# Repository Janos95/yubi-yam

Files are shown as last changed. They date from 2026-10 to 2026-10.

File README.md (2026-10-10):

# yubi-yam

Toyota / AIRoA's [YUBI](https://yubi.airoa.io/) robot gripper, adapted to the
[I2RT YAM](https://i2rt.com/products/yam-6-dof-arm) arm and driven by the DM4310 from
the YAM's stock gripper. It runs on the arm's own CAN bus and 24 V, so there's no
Dynamixel, no U2D2, no extra power supply and no extra cable down the arm.

The fingers, gears, camera and camera mount are Toyota's design, unchanged. So the
wrist camera sees the same thing as on a YUBI handheld, and data collected with the
YUBI glove (or Toyota's dataset) matches what this gripper sees on the robot.

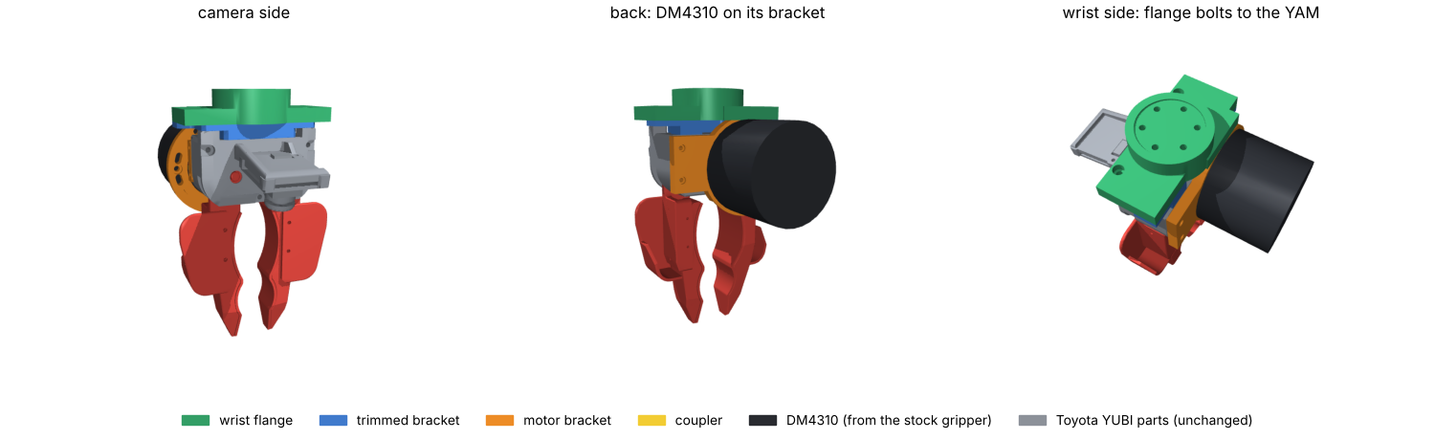
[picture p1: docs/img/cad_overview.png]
CAD overview


## Status

Designed and simulated, **not built yet**.

| What | How it was checked | Result |
|---|---|---|
| New parts fit Toyota's parts and the motor | exact B-rep boolean intersection, every pair (`cad/build.py`) | no overlap |
| Finger travel | exact-mesh collision sweep of both fingers (`sim/finger_sweep.py`) | closed −5.5° (pads touch) to open 36°: **47 mm** between pads, 41.5° of motor travel; new parts never limit it |
| i2RT SDK integration | patch + config installed into a copy of the SDK, then `get_yam_robot(gripper_type=YUBI_4310, sim=True)` | gripper command 0 → 1 drives the finger joint closed → open |
| Grasping | MuJoCo physics: reach down, close on a 30 mm, 50 g cube, lift 10 cm | cube lifts 10 cm, ~17 N pad force at the default gain |
| Reach | exact-mesh collision of the gripper against the arm links over 2,067 poses, compared with the stock gripper | about the same as stock: 256 vs 261 colliding pose/link pairs, all at extreme joint combinations |

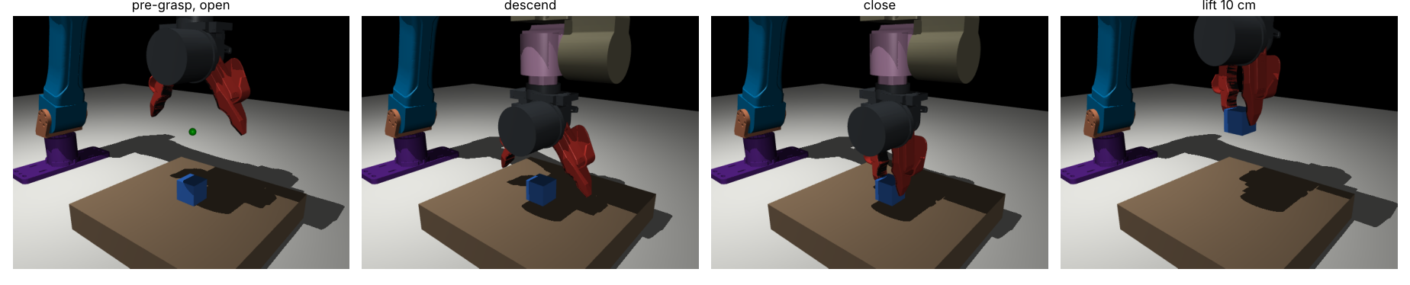
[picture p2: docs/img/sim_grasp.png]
Simulated grasp

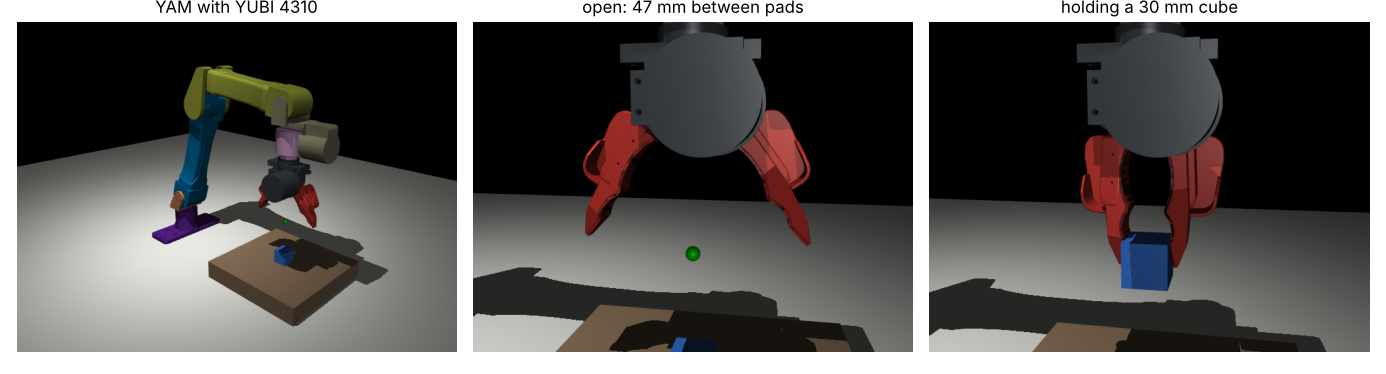
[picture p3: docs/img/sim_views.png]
Simulated views


### Assumptions to check on the real arm

**Checked on the real gripper motor (Oct 9).** The YAM's gripper motor (label
RD-J10D) has the DM4310 face the parts assume: housing Ø57, rotor Ø35, 6× M3 on a
27 mm circle in the rotor (≥7.5 deep), 6× M3 on a 50 mm circle in the front ring
(~4.8 deep). It also has locating pins the reference model lacked: 2× Ø4 on the rotor
(4.2 proud, 23.1 mm circle, 120° apart) and 2× Ø3 on the ring (5.5 proud, opposite
each other, 15° from a screw hole). The coupler has pockets for the rotor pins and the
motor bracket has slots for the ring pins.
The wrist flange also has pockets for the same Ø4 pins, in case the wrist output is
the same motor face (still to confirm once the gripper motor is off the arm).

1. **Wrist screw pattern.** i2RT doesn't publish it, and their meshes have no holes.
   The flange assumes the gripper bolts straight onto the wrist's DM4310 rotor
   (6× M3 on a 27 mm circle around a 35 mm boss); the YAM's last link is 57 mm wide,
   the 4310's diameter. Take the stock gripper off and look. If it differs, change
   `WristInterface` at the top of `cad/build.py` and run `./run_all.sh`. Nothing else
   depends on it.
2. **Wrist face position.** The sim puts the flange face where i2RT's gripper frame
   starts. If the real face sits a few mm away, the tool point in sim is off by that
   much; the hardware is unaffected.
3. **Motor polarity.** Closing should increase the motor reading, as on the stock
   gripper. If the fingers open when commanded closed, set `motor_direction: -1` in
   `yubi_4310.yml`.
4. **Grip force.** `motor_kp: 10` gives roughly 15 N at the pads per N·m of motor
   torque error. Tune it on the real gripper.

## What changes from Toyota's design

| Toyota part | Here |
|---|---|
| Dynamixel XM430-W350-R | DM4310 from the stock YAM gripper |
| Dynamixel horn | `coupler`: DM4310 rotor (6× M3, PCD 27) → YUBI gear shaft. Copies the horn interface, so Toyota's shaft and screws stay unchanged |
| `BRACKET_DYNAMIXEL` | `motor_bracket`: holds the 4310 by its front ring and bolts to the case's existing M2 inserts; the side tab is Toyota's geometry. Has a relief for the thick right finger pad, which reaches 3 mm behind the case |
| `BRACKET_GRIPPER` (machined) | `bracket_trimmed`: the same part, cut back where the bigger motor sits; printable |
| `UR5e_FLANGE` | `yam_flange`: YAM wrist → bracket; also supports the motor bracket from below |

Everything else is built exactly as in Toyota's
[YUBI gripper assembly guide](https://github.com/Toyota/yubi-hw/tree/main/docs/AssemblyInstruction).

The 4310 is bigger and heavier than the Dynamixel (Ø57 × 46 mm, 325 g vs 82 g), so it
hangs behind the case. The whole gripper comes out at about 0.63 kg (stock linear
gripper: about 0.70 kg), with the grasp point 143 mm from the wrist face (stock: 145 mm).

## Build

> **Weekend / first build:** a fully printed version of the gripper and the gloves,
> using only parts available in the US within a couple of days, is described in
> [docs/PRINTED_PROTOTYPE.md](docs/PRINTED_PROTOTYPE.md). The sections below are the
> proper build.

### Print

STEP and STL files are in `cad/out/` (in Toyota's assembly coordinates; STEP is best
for re-orienting in a slicer). PETG or PLA+, 3 walls.

| Part | Orientation | Infill | Note |
|---|---|---|---|
| `yam_flange` | wrist face down | 50 % | |
| `motor_bracket` | motor side down (side tab up) | 60 % | carries the motor's torque |
| `bracket_trimmed` | flat, as Toyota's | 50 % | or machine it in aluminium like Toyota |
| `coupler` | rotor side down | 100 % | or machine it in aluminium; it carries the full gripper torque |

Plus Toyota's printed gripper parts (case, upper plate, fingers, pads, flaps), per
their BOM and print settings.

### Hardware beyond Toyota's BOM

The full shopping list, with MISUMI part numbers and US sources, is in
[docs/BOM_US.md](docs/BOM_US.md).
The [proposed October 9 shopping list](docs/SHOPPING_LIST_2026-10-09.md) records the
prepared vendor carts, printed-prototype substitutions, Hayward pickup and
unconfirmed delivery details. Nothing has been ordered.

| Joint | Qty | Fastener |
|---|---|---|
| wrist flange → YAM wrist | 6 | M3×10 socket head (if the wrist is the assumed 4310 pattern) |
| coupler → DM4310 rotor | 6 | M3×6 low head (DIN 7984) |
| DM4310 → motor bracket | 4 | M3×8 low head (DIN 7984) |
| motor bracket → case back | 2 | M2×8 low head, into the case's existing M2 inserts |
| flange + bracket → upper plate | 2 | M3×12 socket head (replaces Toyota's M3×8 there) |
| inserts | 4 + 2 | M2 heat-set, 3.0 mm OD × 3 mm (as Toyota's SB-203030) in the coupler; M3 heat-set, 4 mm OD × 5 mm in the flange |

Reused from Toyota's BOM: the shaft-to-horn screws (now into the coupler), the
side-tab screws, and the two bracket screws at the flange's ears. Not needed: the
Dynamixel and its screws, the UR5e flange and its screws and pins.

### Assemble

1. Take the stock gripper off the YAM and check the wrist pattern (see above). Take
   the DM4310 out of the stock gripper.
2. Coupler onto the 4310 rotor (6× M3×6). 4310 onto the motor bracket (4× M3×8,
   heads in the counterbores on the case side).
3. Toyota's gear shaft onto the coupler with its 4 M2 screws, as it went onto the horn.
4. Build Toyota's gripper with `bracket_trimmed` in place of `BRACKET_GRIPPER`. Where
   their guide fits the Dynamixel, slide the shaft in and screw the motor bracket to
   the case (2× M2 at the back, 2× M2 into the side).
5. Wrist flange onto the YAM (6× M3×10).
6. Gripper onto the flange: 2× M3×8 from the top through the bracket ears, 2× M3×12
   from below through flange and bracket into the upper plate.
7. Plug the 4310 into the wrist connector the stock gripper used, and run the camera's
   USB cable along the arm.

## Software

```bash
git clone https://github.com/i2rt-robotics/i2rt
./sdk/install.sh ../i2rt        # 4-line patch + config + MuJoCo model
```

```python
from i2rt.robots.get_robot import get_yam_robot
from i2rt.robots.utils import GripperType

robot = get_yam_robot(channel="can0", gripper_type=GripperType.YUBI_4310)
```

It's the same motor on the same CAN ID as the stock gripper. On first start the SDK
calibrates the gripper the same way it does the stock one: it drives gently to the
closed stop (pads touching) and the open stop (fingers against the case). Because the
travel is less than one motor turn, you can then write the measured limits into
`gripper_limits` in `yubi_4310.yml` and set `needs_calibration: false`.

The patch was made against i2rt `120c3c8` (pinned in `third_party/i2rt`).

## Reproduce

```bash
git submodule update --init
pip install -r requirements.txt
./run_all.sh
```

| Step | Script | Output |
|---|---|---|
| parts, interference check, sim meshes | `cad/build.py` | `cad/out/`, `sim/assets/` |
| finger travel | `sim/finger_sweep.py` | `sim/finger_travel.json` |
| i2RT model + config | `sim/build_model.py` | `sdk/overlay/` |
| SDK, grasp and reach checks | `sim/check_sim.py` | `sim/check_report.json`, `docs/img/` |

All dimensions come from published CAD:

- **YUBI:** Toyota's STEP files, exact.
- **YAM:** i2RT's MuJoCo models.
- **DM4310:** checked against Damiao's model as published in OpenArm v1.1 (used for
  measurements only; this repo doesn't contain it).

## Layout

```
cad/build.py           parametric parts, built from Toyota's CAD
cad/out/               STEP + STL of the new parts, build_summary.json
cad/printed.py         fully printed prototype parts -> cad/out/printed/
cad/vendor/            Adafruit AS5600 board model (MIT) for the glove fit check
sim/                   travel sweep, i2RT model generator, checks
sdk/                   i2RT patch, overlay (config, model, meshes), install.sh
docs/                  parts list, printed-prototype guide, figures
third_party/yubi-hw    Toyota's YUBI hardware (submodule)
third_party/i2rt       i2RT SDK (submodule)
```

## Licence

Hardware design files (`cad/`, the meshes in `sim/assets/` and `sdk/overlay/`) are
derived from Toyota's YUBI and released under
[CERN-OHL-W-2.0](LICENSE), like the original. Code is under [MIT](LICENSE-MIT). See
[NOTICE.md](NOTICE.md) for credits.

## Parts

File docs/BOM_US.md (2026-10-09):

# Parts list — US sourcing

Scope: **one YAM robot gripper + one right-hand YUBI data-collection glove**.
Target: **delivery to San Francisco 94158, or Bay Area pickup, by Friday October 9, 2026**.
Prices initially checked October 6, 2026 (Pacific time); selected cart contents and
prices updated October 7. USD, before tax unless stated. The purchase quantities
cover **one robot and one right-hand glove**, plus a spare Adafruit 6357 board and
Radial 9042 magnet (two of each bought). Buy one of each shared pack. Status October 8
evening: the M5 screws are bought; Friday arrival is no longer possible for MISUMI,
McMaster or DigiKey (expect Monday October 12). See the shopping list for details.
Nothing in this list has been ordered. Stock and delivery estimates must be checked again at checkout.

See the [proposed October 9 shopping list](SHOPPING_LIST_2026-10-09.md) for the prepared
carts and the [printed prototype](PRINTED_PROTOTYPE.md) for the weekend substitutions.
The prototype uses printed drive parts/adapters, three 695ZZ bearings with printed
shims, and a stock M5 socket-head screw. Keep the late precision parts in a separate
proper-build shipment.

**Proper-build sourcing is not complete under the Friday constraint.** The exact
gears and stepped shaft currently ship after Friday. Custom machining, bearings, inserts and several
small precision parts still need confirmation. A catalog link does not mean a part is
available in time. We have not established a lowest delivered price for the whole build.

Compare **whole-order cost**: required packs + shipping + rush/setup charges + tax or
import fees. Consolidate orders, but do not let one backordered item delay stocked items.
“Ships October 8” is not “arrives October 8.” MISUMI express eligibility is part-specific;
the general express-service page is not a delivery commitment.

## Already available / excluded

- Reuse the stock YAM gripper's **DM4310**; no Dynamixel, U2D2 or separate Dynamixel power supply.
- Computer, recording software and USB connections are already available.
- Reuse the **Quest 3** and its right Touch Plus controller, assuming the original controller is available.
- Wear the headset for the first iteration: **no headset mount, extrusion rig or chest mount** to buy.
- The **controller holder attached to the glove** is still required; it is a printed part.
- This is a one-glove hardware list, not a claim that Toyota's default two-hand recording configuration
  already works with one glove and a moving headset. Check the selected recording configuration,
  world-frame controller poses, calibration and synchronization before collecting training data.

Sources: [Toyota robot BOM](https://github.com/Toyota/yubi-hw/blob/main/docs/BOM/YUBI%20Gripper_DYNAMIXEL_BOM.md),
[Toyota glove BOM](https://github.com/Toyota/yubi-hw/blob/main/docs/BOM/YUBI%20Glove%20Assy_BOM.md),
[recording software](https://github.com/airoa-org/yubi-sw).

## Print versus machine

The preferred machining set is **five parts**, quantity one each. The two finger
attachments are a separately priced upgrade. No machining order should use the
print-oriented adapter STEP files without resolving their threaded features.

| Part | Process for this build | Source / release requirement |
|---|---|---|
| Toyota `GEAR SHAFT` | Machine, A2024 as Toyota specifies | [Toyota STEP](https://github.com/Toyota/yubi-hw/tree/main/STEP/gripper); preserve journal fits and coaxiality. Printing is only an assembly mock-up, not an accuracy-equivalent substitute. |
| YAM `coupler` | Prefer machined aluminum | [STEP](../cad/out/coupler.step); convert four M2 heat-set-insert pockets to properly designed metal threads. |
| YAM `motor_bracket` | Prefer machined aluminum | [STEP](../cad/out/motor_bracket.step); load-bearing motor support. |
| YAM `bracket_trimmed` | Prefer machined aluminum | [STEP](../cad/out/bracket_trimmed.step); replaces Toyota's machined `BRACKET_GRIPPER`. |
| YAM `yam_flange` | Prefer machined aluminum | [STEP](../cad/out/yam_flange.step); convert two M3 insert pockets to metal threads and measure the real wrist before release. |
| Toyota `FINGER ATTACHMENT_L/R` (2) | Optional A2024 machining upgrade | Toyota allows machined A2024 or printed PLA. Price separately; printing does not guarantee equal stiffness/precision. |
| Robot case, upper plate/camera bracket, three pad bodies, two flaps | Print as in Toyota's design | [STL/gripper](https://github.com/Toyota/yubi-hw/tree/main/STL/gripper); inspect bearing seats and assembly fit. |
| Glove upper/under plates, two geared fingers, two flaps, grip, right controller holder, PCB/cable covers | Print; use the adapted AS5600 upper plate | [Printed prototype](PRINTED_PROTOTYPE.md) for `glove_upper_plate_as5600`; other parts from [STL/glove](https://github.com/Toyota/yubi-hw/tree/main/STL/glove). Right hand uses `FINGER with Gear_t30_R` and `FINGER with Gear_t20_L`. No bought metal gears for the glove. |

The YAM adaptation is designed/simulated, **not physically validated**. Its wrist pattern
(six M3 holes on a 27 mm pitch circle and a 35 mm boss) is an assumption pending measurement.
The coupler/flange insert pockets are not suitable tap-drill holes as exported. Request
critical fits, tolerances and material approval before manufacture; 6061-T6 is a quote
candidate for new adapters, not an automatic substitute for Toyota's A2024 parts.

### Local machining candidates

| Shop | Relevant published capability | Price + Friday status |
|---|---|---|
| [finalREV, Berkeley](https://www.finalrev.com/services/millturn) | Advertises same-day Bay Area parts, single-part minimum and local pickup. [5-axis service](https://www.finalrev.com/services/5-axis-cnc) for larger/prismatic work. | **RFQ sent October 6; response pending.** Millturn stock limit is 1-inch round; the gear shaft fits that diameter, the 32 mm gear does not. Confirm A2024 availability. |
| [RivCut, Union City](https://www.rivcut.com/) | Milling/turning, 2024/6061/7075 aluminum; prototypes advertised as fast as three business days; pickup by appointment. | **Quote required.** No job-specific price, capacity reservation or Friday promise obtained. |
| [twentyfour26, San Francisco](https://twentyfour26.com/) | Rapid prismatic machining in 6061-T6. | Conditional bracket backup: minimum internal radius and standard tolerances need checking against these parts. **Quote required.** |

Request one combined quote for the five preferred parts, the two optional finger
attachments separately, and modification/machining of the late bought parts below.
Require itemized setup, design revision, inspection, rush and pickup/delivery charges.
As-machined/deburred finish avoids unnecessary cosmetic finishing cost. Quotes are not
manufacturing authorization. **finalREV RFQ sent October 6, 2026** with the five-part
base set, two optional finger attachments, source CAD and catalog-part modification
requests. Requested itemized pricing, total pickup/delivery costs and committed Friday
October 9 availability. **Awaiting response; price and Friday capacity are unconfirmed.**
Other supplier RFQs have not been sent. No machining order has been placed.

## Robot motion and alignment parts

All quantities below are for the robot only.

| Qty | Required part / important geometry | Source and observed parts price | Friday status / next route |
|---|---|---|---|
| 2 | `GEAKB1.0-30-6-B-8N-QFC17-M3-LL`; module 1, 30 teeth, 6 mm face, keyed Ø8 bore, QFC17 M3 face-hole feature | [MISUMI USA](https://us.misumi-ec.com/vona2/detail/110300428430/?HissuCode=GEAKB1.0-30-6-B-8N-QFC17-M3-LL), $42.51 each / **$85.02** | **Late:** October 7 cart showed ship October 14. Ask for part-specific express or local modification of a compatible stock gear. Generic 30T/8 mm gears are not drop-in replacements. |
| 1 | `SSFRHQ8-20-F6-P5-T6-Q5-KC8-A12`, configured Ø8 stepped/keyed left finger shaft | [MISUMI USA](https://us.misumi-ec.com/vona2/detail/110300088230/?HissuCode=SSFRHQ8-20-F6-P5-T6-Q5-A12-KC8), **$26.71** | **Late:** displayed ship October 14. Local turning/keyway quote must use the full configured drawing, not only overall diameter/length. |
| 3 | `MTA05-13ZZ DBS`, NSK Micro/ISC angular-contact bearing, nominal 5 × 13 × 5 mm | [MISUMI USA](https://us.misumi-ec.com/vona2/detail/221000531127/?HissuCode=MTA05-13ZZ%20DBS), $23.58 each / **$70.74**; [Volition](https://www.govolition.com/product/V52-MTA05-13ZZ%20DBS) lists the same MISUMI supply | **Unconfirmed:** October 7 cart has no ship date. Volition's estimated three days to ship is not Friday delivery or independent stock. Preserve these bearings for the proper build; 695ZZ plus a printed shim is only the documented prototype stand-in. |
| 3 | `WSSAB10-5-1`, nominal Ø10 OD / Ø5 ID / 1 mm thickness | [MISUMI USA](https://us.misumi-ec.com/vona2/detail/110302677010/?HissuCode=WSSAB10-5-1), $23.42 each / **$70.26** | **Late:** ship October 10. Seek a stocked precision spacer or add to local machining quote. Generic M5 washers are not automatically equivalent. |
| 2 | `KEG3-8`, 3 × 3 × 8 mm, one round end and one square end | [MISUMI USA](https://us.misumi-ec.com/vona2/detail/110302681730/?HissuCode=KEG3-8), $3.90 each / **$7.80**; [Huyett 330303-008](https://www.huyett.com/330303-008) has matching nominal Form AB geometry | **Late** at MISUMI: ship October 10. Huyett is special-order with a $50 minimum, not a verified fast/cheap alternative. Ask shop to supply/finish keys. |
| 1 | Round locating pin `JPBPB2-3` | [MISUMI USA](https://us.misumi-ec.com/vona2/detail/110300557320/?HissuCode=JPBPB2-3), **$7.05** | **Stock/ship candidate:** October 8 dispatch; shipping cost and arrival unquoted. |
| 1 | Diamond locating pin `JPDPB2-3` | [MISUMI USA](https://us.misumi-ec.com/vona2/detail/110300557320/?HissuCode=JPDPB2-3), **$9.89** | **Late:** ship October 15. Ask about a stocked same-fit material variant or local modification of a round pin to the drawing. |

**Precision corrections:** the locating pins are not ordinary Ø2 × 3 mm dowels:
they have a Ø2 press-fit shank, Ø3 positioning head, 4 mm mounting length and 3 mm
positioning length. Preserve the round/diamond pairing. The original washer has ID
5.1–5.3 mm, OD 9.8–10 mm and thickness 1 ±0.05 mm. Verify any replacement's tolerance.

**Cheaper spacer candidate:** [KB3D SS-5101-50 DIN 988 shim rings](https://kb-3d.com/store/inserts-fasteners-adhesives/288-5x10x1mm-shim-ring-washer-pack-of-50-din988-1634423113147.html)
are **$3.79 per pack of 50**, with **two packs in stock** in the retailer listing.
Nominal dimensions are 5 × 10 × 1 mm; stainless steel replaces the original aluminum.
Confirm actual ID/OD/thickness tolerances, shaft/fillet clearance and flat seating
before using them as WSSAB replacements. They are a credible low-cost precision-shim
candidate, not an ordinary M5 washer. Shipping from Ohio must be expedited and quoted;
the retailer publishes a 2 pm Eastern same-day cutoff, not a Friday-arrival guarantee.

[NSK's catalog](https://www.nskmicro.co.jp/english/download/catalog_pdf/bearing/croxy_en.pdf)
explains the angular-contact/preload design. Radwell lists `MTA05-13ZZ DB`, a different
paired configuration, not the specified `DBS`; buying/separating those is **not an
approved substitute** without NSK confirmation. No precision-preserving printed
bearing, key or shaft substitute is selected.

**Concrete gear-blank route for a shop to quote:**
[KHK SSA1-30](https://catalog.khkgears.us/item/spur-gears/hubless-spur-gears-ssa/ssa1-30)
is **$13.45 each / $26.90 for two**, with **five on hand** at the original KHK USA check.
It is unhardened S45C steel, module 1, 30 teeth, 20° pressure angle, Ø8 plain bore,
Ø32 outside diameter, **10 mm face width** and JIS N8 quality. It needs a shop's
geometry review, width reduction to 6 mm, keyway and the configured face features;
tooth accuracy/backlash must also meet the application. It is **a machining blank,
not a drop-in replacement**. Overnight freight and machining/pickup remain unquoted.
Grainger lists this blank for $19.99 but showed October 22 delivery, so its offer
does not meet the deadline. Do not order blanks until a shop accepts the conversion.

## Cameras, glove electronics and shared consumables

| Qty to buy | Part | Source / observed price | Delivery / compatibility |
|---|---|---|---|
| 2 | ELP `USBFHD01M-L180` camera: one robot, one glove | [Amazon US](https://www.amazon.com/dp/B00LQ854AG), **$44.99 each new / $89.98 total** | October 7 check with quantity 2 showed Friday October 9 to 94158 with Prime. The cheaper used-like-new offer now misses Friday. Guest shipping misses Friday; sign-in and selected-offer confirmation required. |
| 1 | Seeed XIAO ESP32C6 `113991254` | [DigiKey](https://www.digikey.com/en/products/detail/seeed-technology-co-ltd/113991254/24613066), **$5.38** | Immediate availability in the prepared cart; combine with perfboard/magnets. Delivery conditional on dispatch and chosen shipping. |
| 2 (1 spare) | Adafruit `6357` AS5600 breakout | [DigiKey 1528-6357-ND](https://www.digikey.com/en/products/detail/adafruit-industries-llc/6357/26832926), **$5.95 each / $11.90** | Immediate availability in the overnight DigiKey cart. Use `glove_upper_plate_as5600` and four extra M2×6 screws. Separate Adafruit cart remains empty. Actual Friday arrival remains unconfirmed. |
| 2 (1 spare) | Diametric encoder magnet, Radial Magnets `9042`, Ø6 × 2.5 mm, N35 | [DigiKey](https://www.digikey.com/en/products/detail/radial-magnets-inc/9042/5640338), **$0.63 each / $1.26** | Immediate availability in the prepared cart. Board ships without a magnet. Use the documented 2 mm sensor gap. Must be **diametrically**, not axially, magnetized. |
| 1 | SparkFun `PRT-08808` perfboard, 25.4 × 25.4 mm | [DigiKey](https://www.digikey.com/en/products/detail/sparkfun-electronics/08808/7387401), **$2.96** | Exact original perfboard; Immediate availability in the prepared cart. |
| As needed | Pin headers / short hookup wires / solder | Check XIAO package and existing supplies; Toyota lists four header pieces | Header installation is required. Avoid ordering a new soldering kit unless missing. |
| 0 (already owned) | Grip rubber; original 1.5 mm `PX-10H15 HYPER V` | Janos's Everbilt rubber packing sheet, 6 × 6 in × 1/16 in (Home Depot 1006950747), already tested on wires. Fallback if grip is insufficient: [RAPOLL solid neoprene, 12 × 12 in × 1/16 in](https://www.amazon.com/dp/B0BKQRN7S6), $6.89 | **Thickness substitution** (nominal 1.59 mm vs 1.5 mm): recalibrate the jaw's closed position. Glue with Loctite Ultra Gel Control. |
| 1 alternative pack | Nominal 1.5 mm silicone sheet | [PATIKIL, five Ø100 mm discs](https://www.amazon.com/dp/B0G2JR4VFQ), **$9.21 + free Prime shipping**, Thursday shown in search | Alternative to neoprene, not an additional purchase. Check cutting layout and suitable silicone adhesive; grip performance is unvalidated. [Original Hyper V](https://nisshinrubber-metalcraft.com/products/hyperv%E3%82%B7%E3%83%BC%E3%83%88-px-10h-15-%E8%80%90%E6%B2%B9w270-l270-h1-5mm) remains the reference. |
| 1 band from pack | Return band, original Japanese No.16 | [MOWPOG #16 pack](https://www.amazon.com/dp/B0FCM95WH7), **$5.99 + free Prime shipping**, Thursday October 8 shown | Listing specifies 2.37 in folded length and 0.06 in width/thickness. Check return force and full travel; the size number alone is not equivalence. Reusing a suitable existing band avoids buying hundreds for one glove. |
| 0 | USB data cables/connections | Already available | Verify connector ends on the actual camera and XIAO; do not blindly order two USB-C cables. |

[DigiKey US shipping rates](https://www.digikey.com/en/help-support/delivery-information/delivery-time-and-cost):
two-day air **$13.99/order**, overnight PM **$26.99/order**. The prepared cart contains
one each of XIAO and perfboard plus two each of Adafruit 6357 and Radial 9042 (one
spare), **$21.50 parts**, with **FedEx Overnight P.M. selected**. Estimated tariff is
about **$0.68** (October 7 estimate scaled; recheck), for about **$49.17 before tax**.
Friday arrival to 94158 is not displayed. DigiKey warns that processing may take an
extra business day: overnight requires dispatch by Thursday October 8. `MIKROE-4204`
does not fit the glove and is removed; the `AS5601-SO_EK_AB` fallback is dropped too.
The separate Adafruit cart remains empty; the 6357 board is in the DigiKey cart.
Solder VIN (3.3 V), GND, SCL and SDA directly to the XIAO; no QT cable is needed.

## Screws — consolidated quantities for both builds

Counts include one robot and one right glove. Standard socket heads and low/ultra-low
heads are separate requirements. Lengths are under-head lengths. Ordinary screws use
M2 × 0.4, M2.5 × 0.45 and M3 × 0.5 threads.

| Robot | Glove | Buy/use total | Screw | Source / current status |
|---:|---:|---:|---|---|
| 4 | 8 | 12 | M2 × 6, standard socket head | [mxuteuk M2-only 520-piece kit](https://www.amazon.com/dp/B0C6M6MJ8M), **$8.99**, explicitly lists **30 M2×6**; Friday with Prime shown. Glove count includes four extra AS5600 mount screws. Original mixed kit removed: it contains M2×12/16, no M2×6. |
| 2 | 2 | 4 | M2.5 × 6, standard socket head | Included in the VGBUY M2.5 kit below; [McMaster 91290A101](https://www.mcmaster.com/91290A101/) fallback, $11.81/50. |
| 0 | 2 | 2 | M2.5 × 8, standard socket head | Included in the VGBUY M2.5 kit below; [McMaster 91290A006](https://www.mcmaster.com/91290A006/) fallback, $11.71/100. |
| 4 | 0 | 4 | M2.5 × 10, standard socket head | [VGBUY M2.5 1001-piece kit](https://www.amazon.com/dp/B0FJ1YMG3J), **$9.99 guest cart**, advertised Prime deal $7.99; October 8 with Prime shown. Also covers M2.5 × 6/8. [McMaster 91290A007](https://www.mcmaster.com/91290A007/) fallback is $11.03/100. |
| 3 | 3 | 6 | M2.5 × 15, standard socket head | [McMaster 91290A009](https://www.mcmaster.com/91290A009/), **$4.25/10**, Thursday delivery shown; final shipping unquoted. |
| 0 | 1 | 1 | M3 × 6, standard socket head | Included in the ALLWIN M3 kit below. |
| 4 | 0 | 4 | M3 × 8, standard socket head | Included in the ALLWIN M3 kit below. |
| 6 | 0 | 6 | M3 × 10, standard socket head | [ALLWIN M3 400-piece kit](https://www.amazon.com/dp/B0F5QKDW7Y), **$5.79 guest cart**, advertised Prime deal $4.63; October 9 with Prime shown. Includes 30 screws of this length plus M3 × 6/8/12/16/20. |
| 2 | 0 | 2 | M3 × 12, standard socket head | Included in the ALLWIN M3 kit above. |
| 6 | 0 | 6 | M2 × 5, ultra-low head: Ø4 × 0.5 mm head | [MISUMI CBSTBR2-5](https://us.misumi-ec.com/vona2/detail/110302280540/?HissuCode=CBSTBR2-5), **$5.24 each / $31.44**; same steel/geometry, black nickel instead of white. October 8 dispatch shown. Original CBSTNR2-5 ships October 10. |
| 4 | 0 | 4 | M3 × 8, ultra-low head: Ø6 × 0.8 mm head | [MISUMI CBSTNR3-8](https://us.misumi-ec.com/vona2/detail/110302280540/?HissuCode=CBSTNR3-8), **$5.05 each / $20.20**, October 8 dispatch shown. |
| 6 | 0 | 6 | M3 × 6, low head for rotor → coupler | [McMaster 92855A307](https://www.mcmaster.com/92855A307/), **$7.30/25**, Ø5.5 × 2 mm head, Thursday 7–9 am shown. |
| 4 | 0 | 4 | M3 × 8, low head for stator → motor bracket | [McMaster 92855A309](https://www.mcmaster.com/92855A309/), **$7.55/25**, 18-8 stainless, DIN 7984, Ø5.5 × 2 mm head, Thursday shown. [Alloy-steel 93070A064](https://www.mcmaster.com/93070A064/) is $13.62/50 if higher strength is required. |
| 2 | 0 | 2 | M2 × 8, low head for motor bracket → case back | [McMaster 92855A839](https://www.mcmaster.com/92855A839/), **$20.40/10**, Ø3.8 × 1.35 mm head, Thursday 7–9 am shown. |

McMaster dates above are displayed site estimates; the final destination/shipping
charge was not entered or quoted. MISUMI stocked rows also require a delivered quote.
The original [888-piece mixed kit](https://www.amazon.com/dp/B0G8F366MV) has only
M2×12/16 in its size diagram and cannot cover M2×6. The replacement M2-only kit's
packaging text explicitly lists 30 M2×6, leaving **18 spare** after the required 12.
Its size diagram has mislabeled entries, so the count is taken from the packaging
text. The two CBSTNR3-5 mount screws per glove are no longer required by the AS5600
plate. Do not buy every fallback pack as well as the selected kits.

The prepared standard-screw combination is the **$8.99 M2 kit + $9.99 M2.5 kit +
$5.79 M3 kit + $4.25 McMaster M2.5 × 15 pack = $29.02** before freight/tax.
Advertised Prime deals of $7.99 for M2.5 and $4.63 for M3 would reduce it to **$25.86**
if applied after sign-in. All three Amazon kits show delivery by Friday with Prime,
**plus the McMaster order's shipping and tax**.
This covers every standard screw length above; special low/ultra-low heads are extra.
Amazon search dates must be rechecked for the selected offer at checkout. Prime sale
prices and the displayed nightly delivery cutoffs may expire.

DIN 7984 and ordinary “low head” screws do **not** replace Toyota's ultra-low heads.
The new adapter counterbores and screw engagement still need checking on the machining
revision. Follow the manufacturer's reduced tightening torque for ultra-low heads.
The listed 18-8 low-head screws have 70,000 psi tensile strength; confirm required
joint preload/strength before substituting them for higher-strength alloy steel.

## Printed-prototype stand-ins

These are temporary purchases for the [printed prototype](PRINTED_PROTOTYPE.md),
not precision-equivalent replacements for the proper-build parts.

| Buy qty | Stand-in | Source / price | Fulfillment / use |
|---|---|---|---|
| 1 pack of 10; use 3 | 695ZZ deep-groove bearings, 5 × 13 × 4 mm | [KABOBEARING](https://www.amazon.com/dp/B0CRP3K8ZF), **$6.99** guest cart; advertised Prime deal $5.59 | October 8 with Prime shown. Cheapest matching Friday-capable pack found in the ascending-price search. Print three `bearing_shim_1mm` parts under the outer races. |
| 1 pack of 2; use 1 | M5 × 0.8 × 70 mm socket-head cap screw | [Home Depot Everbilt 844868, SKU 540934](https://www.homedepot.com/p/204283625), **$3.97** | **Bought** at Hayward on October 7. Use one screw and keep one spare. |

## Inserts for printed parts

| Robot | Glove | Total | Original specification | Sourcing status |
|---:|---:|---:|---|---|
| 4 | 0 | 4 | `SB-203030`: M2, nominal body Ø3 / knurl Ø3.3, length 3 mm | Exact US stock unresolved; generic M2 insert must match the actual printed hole and installation recommendation. |
| 5 | 5 | 10 | Toyota calls out `SB-264040`, nominal body Ø4 / knurl Ø4.3, length 4 mm | **Thread discrepancy to resolve:** assembly uses M2.5 screws; current Tokai catalog calls M2.5 `SB-254040`, while `SB-264040` is M2.6. Do not order M2.6 blindly. |
| 4 | 0 | 4 | `SB-304550`: M3, nominal body Ø4.5 / knurl Ø4.8, length 5 mm | Exact US stock unresolved. Not “M3 Ø4 × 5”; check fit before choosing another brand. |
| 0 | 2 | 2 | `SB-304540`: M3, nominal body Ø4.5 / knurl Ø4.8, length 4 mm | Exact US stock unresolved. |

[Tokai dimensions](https://tokai-mmc.co.jp/insert/seihin_sb.html) and
[catalog](https://www.tokai-mmc.co.jp/insert/catalog/SB.pdf).
A different insert is acceptable only after adapting/checking the printed hole, pullout
resistance and surrounding wall; “any heat-set kit works” was incorrect.

**Fast US candidates, requiring printed-hole adaptation/fit validation:**

- [KADRICK 520-piece kit](https://www.amazon.com/dp/B0D5V3TZLB), **$15.98**, includes
  M2 × 3 mm long (listed OD 3 mm), M3 × 4 mm and M3 × 5 mm (listed OD 4.5 mm).
- [KADRICK M2/M2.5 300-piece kit](https://www.amazon.com/dp/B0FD7DQS8Y), **$9.99**,
  includes M2.5 × 4 mm long, listed OD 3.5 mm, thread pitch 0.45 mm.
- Both product pages showed **free Prime delivery Thursday October 8** to 94158.
  Together **$25.97 delivered before tax** at the checked offers. These are not the
  original Tokai insert shapes/diameters. Preserve hole centers, select pilot holes
  for these inserts, and check wall thickness, installation, screw engagement and
  pullout/torque resistance before using them in load-bearing printed parts. Do not
  install a loose insert into the original larger hole and call it equivalent.

This closes the supply search for candidate inserts, **not their fit/strength
qualification**. Exact Tokai US stock remains unresolved. A cheaper $9.99 Dianrui
assortment was rejected as a complete kit because it lacks the needed M2 × 3 and
M3 × 5 lengths; the $9.99 KADRICK M3-only kit showed October 12 delivery.

For the **machined coupler/flange**, metal threads replace the adapter inserts.
For the printed pair, add **four M2×3 and two M3×5 inserts** to the base counts.
The selected single kits cover **8 M2×3 / 60 available**, **10 M2.5×4 / 60**,
**6 M3×5 / 50**, and **2 M3×4 / 50**. These counts include the printed adapters;
keep the existing printed-hole fit/strength checks.

## Glove-only adjustment hardware

| Qty | Part | Source / parts price | Friday status |
|---|---|---|---|
| 4 | `JZF8-5` POM flanged bushings, nominal ID8 / OD10 / overall length5 mm | [MISUMI USA](https://us.misumi-ec.com/vona2/detail/110302640340/?HissuCode=JZF8-5), **$2.70 each / $10.80** | October 8 dispatch shown; delivery/shipping quote pending. |
| 1 | M3 × 6 long knurled screw, original `LRLM3-6` | [MISUMI LRLB3-6](https://us.misumi-ec.com/vona2/detail/110300245210/?HissuCode=LRLB3-6), **$6.06** | Same geometry in 303 stainless, Ø5.5 head × 10 mm high; October 8 dispatch. Original plated-steel LRLM3-6 is $5.78 but ships October 12. |
| 1 | `AJKTNS5-70`, M5 × 0.8, 70 mm adjustment screw | [MISUMI USA](https://us.misumi-ec.com/vona2/detail/110300599320/?HissuCode=AJKTNS5-70), **$15.14**; [black-oxide steel AJKTN5-70](https://us.misumi-ec.com/vona2/detail/110300599320/?HissuCode=AJKTN5-70), **$7.23** | **Both late:** ship October 12. Add to local-shop request. A stock bolt + knob needs tip/head/clearance review, not just a matching M5 thread. |
| 1 | `HNTT5-5` M5 pre-insertion T-slot nut | [MISUMI USA](https://us.misumi-ec.com/vona2/detail/110302246150/?HissuCode=HNTT5-5), **$0.73** | October 8 dispatch shown; delivered price/date pending. Exact pocket geometry, not a generic “2020” nut. |

## Order groups and shipping comparison

The [proposed shopping list](SHOPPING_LIST_2026-10-09.md) records the six prepared
carts, purchase quantities and shared-pack count audit. These remain **partial
order groups**, not a complete build budget: tax, unquoted freight and custom
machining are excluded. Nothing has been ordered. Material/fit substitutions still
need the checks above.

| Order group | Checked contents | Parts / shipping / status |
|---|---|---|
| Amazon | Two new cameras; one each M2/M2.5/M3 screw kit, #16 band pack, both KADRICK kits and ten-pack of 695ZZ bearings | **$153.70 parts** (neoprene dropped). Prime delivery dates to be reconfirmed; guest shipping is slower. Advertised Prime deals would reduce parts to about $149.14 if applied after sign-in. |
| McMaster | One M2.5×15 ten-pack; one each of the three low-head packs | **$39.50 + shipping + tax** in the unsubmitted cart. Site estimates Thursday; destination-specific freight/arrival remain unquoted. Shared low-head packs cover 6/25 M3×6, 4/25 M3×8 and 2/10 M2×8. |
| MISUMI stocked | CBSTBR2-5 ×6, CBSTNR3-8 ×4, JZF8-5 ×4, LRLB3-6 ×1, HNTT5-5 ×1, JPBPB2-3 ×1 | **$76.28 + shipping + tax**. October 8 dispatch displayed; next-day shipping needs a quote/login to confirm Friday arrival. CBSTNR3-5 removed. Keep late items separate. |
| DigiKey | One each XIAO and perfboard; two each Adafruit 6357 and Radial 9042 (one spare) | **$21.50 parts + $26.99 selected overnight PM + about $0.68 estimated tariffs = about $49.17 before tax**. All Immediate; Friday arrival no longer possible. Separate Adafruit cart remains empty. |
| Home Depot, Hayward | One two-pack of Everbilt M5×0.8×70 socket-head screws | **$3.97 + tax, bought October 7.** Use one screw, keep one spare. |
| MISUMI late / proper build | Two gears, one stepped shaft, three MTA05-13ZZ DBS, three spacers, two keys, one diamond pin, one AJKTNS5-70 | **$285.56 + shipping + tax** in the separate cart. Freight unselected/login required. Gears/shaft dispatch October 14, pin October 15, bearings undated. Request partial shipment. |

The five prototype/shared groups total **$322.62**, including selected DigiKey freight
and estimated tariffs, before sales tax and unquoted McMaster/MISUMI freight. The
late cart adds **$285.56**, making **$608.18** on the same incomplete basis.
Custom machining (five preferred parts), adhesive and any missing wiring/printing
supplies are excluded. The KHK gear-blank conversion remains a separately quoted
alternative, not an additional purchase in these carts. Selecting the alloy-steel
M3×8 low-head pack instead of stainless adds $6.07.

[MISUMI shipping guidance](https://us.misumi-ec.com/guide/faq/shipping.html) and
[McMaster delivery information](https://www.mcmaster.com/info/delivery).
Do not assume free MISUMI/McMaster shipping or substitute a catalog dispatch date for
arrival. Review the selected Prime offers and consolidated checkout totals before paying.

## Delivery checks before ordering

For the printed prototype, confirm Amazon Prime offers, quoted MISUMI next-day and
McMaster arrival to 94158, and DigiKey dispatch despite the processing warning.
All glove electronics are consolidated on DigiKey overnight. The Home Depot screws
are already bought. The full checklist is in the [proposed shopping list](SHOPPING_LIST_2026-10-09.md).

## What still prevents a complete proper build by Friday

1. Confirm a shop's **price and Friday pickup commitment** for the five machining
   parts; release revised coupler/flange drawings and verify the physical wrist.
2. Obtain a Friday route for **two finished gears and the stepped shaft**; exact catalog
   dates miss. KHK has a priced, on-hand gear blank for a shop to assess and modify.
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

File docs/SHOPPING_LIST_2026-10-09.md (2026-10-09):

# Proposed shopping list — October 9 printed prototype

Checked **October 7, 2026, Pacific time**, for delivery to **San Francisco 94158**
by **Friday October 9**, with the M5 screw picked up at **Hayward Home Depot**.

> **Status, Thursday October 8 evening:** the M5 screws are bought (Hayward, October 7).
> Same-day cutoffs for Friday arrival have passed at MISUMI (6 p.m. Eastern) and for
> DigiKey overnight, so carts placed from now on should expect **Monday October 12**
> for MISUMI, McMaster and DigiKey; Amazon Prime may still deliver Friday or Saturday.
> The neoprene sheet is dropped: Janos already has 1/16 in rubber sheet that grips
> wires well. A spare AS5600 board and magnet are added in case one is damaged while
> soldering.

Build scope: **one YAM robot gripper and one right-hand YUBI glove**, printed for
the weekend and upgraded with the precision parts later. The glove gets one XIAO,
perfboard, Adafruit 6357 board and Radial 9042 magnet; buy two boards and two magnets
so one of each is a spare. Buy one of each shared pack.

The source requirements are [BOM_US.md](BOM_US.md) and
[PRINTED_PROTOTYPE.md](PRINTED_PROTOTYPE.md). This proposal records the prepared
cart contents. **Nothing has been ordered, reserved, checked out or paid.** Prices
and stock are a dated snapshot; Friday delivery is not confirmed for every vendor.

## Changes from the original list

- Use Adafruit 6357 AS5600 with `glove_upper_plate_as5600`. Remove MIKROE-4204
  because it does not fit; drop the AS5601-SO_EK_AB fallback.
- Buy two Radial 9042 diametric magnets (one spare); the Adafruit board includes no magnet.
- Add four M2×6 socket-head screws per glove for the encoder. One robot and one
  glove need **12 total: 4 robot + 4 original glove + 4 encoder mount**.
- Replace the mxuteuk 888-piece mixed screw kit (`B0G8F366MV`): its diagram shows
  M2×12/16 only, with no M2×6. The $8.99 M2-only kit (`B0C6M6MJ8M`) explicitly lists
  **30 M2×6 in its packaging text**, leaving 18 spare. The diagram has mislabeled
  sizes; use the explicit packaging text for the count. The existing M2.5 and M3
  kits cover the other standard screws, so there are still three screw kits.
- Remove CBSTNR3-5 ×2; the new encoder plate uses the four M2 mount screws.
- Use three 695ZZ bearings with three printed 1 mm outer-race shims and one stock
  M5×0.8×70 socket-head screw for the prototype. Keep the original precision parts
  in the separate late shipment.

## Friday carts and pickup

Quantities below are **units/packs to buy**, with assembly quantities called out
where a pack contains surplus. Prices are the displayed guest-cart prices, before
tax and freight unless stated.

### Amazon — $153.70 parts

| Part | Buy qty | Pack / assembly use | Unit price | Line total |
|---|---:|---|---:|---:|
| [ELP USBFHD01M-L180, new](https://www.amazon.com/dp/B00LQ854AG) | 2 | one camera for the robot and one for the glove | $44.99 | $89.98 |
| [mxuteuk M2 socket-head screw kit](https://www.amazon.com/dp/B0C6M6MJ8M) | 1 | 520-piece kit; 30 M2×6, use 12, leaving 18 spare | $8.99 | $8.99 |
| [VGBUY M2.5 screw kit](https://www.amazon.com/dp/B0FJ1YMG3J) | 1 | M2.5×6: 50 available/4 needed; ×8: 40/2; ×10: 40/4 | $9.99 | $9.99 |
| [ALLWIN M3 screw kit](https://www.amazon.com/dp/B0F5QKDW7Y) | 1 | M3×6/8/10/12: 30 each; need 1/4/6/2 | $5.79 | $5.79 |
| [MOWPOG #16 return bands](https://www.amazon.com/dp/B0FCM95WH7) | 1 | 700-band pack; use one band | $5.99 | $5.99 |
| [KADRICK M2–M5 insert kit](https://www.amazon.com/dp/B0D5V3TZLB) | 1 | M2×3: 60/8; M3×4: 50/2; M3×5: 50/6; includes printed adapter inserts | $15.98 | $15.98 |
| [KADRICK M2/M2.5 insert kit](https://www.amazon.com/dp/B0FD7DQS8Y) | 1 | M2.5×4: 60/10 needed | $9.99 | $9.99 |
| [KABOBEARING 695ZZ, 5×13×4 mm](https://www.amazon.com/dp/B0CRP3K8ZF) | 1 | 10 bearings; use three for one printed gripper | $6.99 | $6.99 |

All selected offers show delivery by Friday **with Prime** to 94158. The two new
cameras (quantity two checked), replacement M2 kit and M3 kit show October 9;
the other items show October 8. Guest shipping misses Friday. Prime sign-in and offer confirmation are
still required. The cheaper used camera offer misses Friday. The bearings were the
cheapest matching pack found with delivery by Friday in the ascending-price search.

Advertised Prime prices of $7.99 for the M2.5 kit, $4.63 for M3 and $5.59 for the
bearings would reduce this cart to about **$149.14** if applied after sign-in.
Grip rubber is not bought: Janos's Everbilt 1/16 in rubber packing sheet (two 6×6 in
sheets, already tested on wires) covers the four pad pieces.

### McMaster — $39.50 parts

| Part | Buy qty | Pack / assembly use | Line total |
|---|---:|---|---:|
| [91290A009 — M2.5×15 socket head](https://www.mcmaster.com/91290A009/) | 1 | one ten-pack, 10 screws available; use 6 | $4.25 |
| [92855A307 — M3×6 low head](https://www.mcmaster.com/92855A307/) | 1 | one pack, 25 screws available; use 6 | $7.30 |
| [92855A309 — M3×8 low head](https://www.mcmaster.com/92855A309/) | 1 | one pack, 25 screws available; use 4 | $7.55 |
| [92855A839 — M2×8 low head](https://www.mcmaster.com/92855A839/) | 1 | one pack, 10 screws available; use 2 | $20.40 |

The site displays October 8 delivery. The service, freight charge and destination-specific
arrival to 94158 remain unquoted; the checkout/contact flow was not entered.

### MISUMI stocked shipment — $76.28 parts

| Part | Buy qty | Unit price | Line total |
|---|---:|---:|---:|
| [CBSTBR2-5](https://us.misumi-ec.com/vona2/detail/110302280540/?HissuCode=CBSTBR2-5) | 6 | $5.24 | $31.44 |
| [CBSTNR3-8](https://us.misumi-ec.com/vona2/detail/110302280540/?HissuCode=CBSTNR3-8) | 4 | $5.05 | $20.20 |
| [JZF8-5](https://us.misumi-ec.com/vona2/detail/110302640340/?HissuCode=JZF8-5) | 4 | $2.70 | $10.80 |
| [LRLB3-6](https://us.misumi-ec.com/vona2/detail/110300245210/?HissuCode=LRLB3-6) | 1 | $6.06 | $6.06 |
| [HNTT5-5](https://us.misumi-ec.com/vona2/detail/110302246150/?HissuCode=HNTT5-5) | 1 | $0.73 | $0.73 |
| [JPBPB2-3](https://us.misumi-ec.com/vona2/detail/110300557320/?HissuCode=JPBPB2-3) | 1 | $7.05 | $7.05 |

All six lines show stock and October 8 **dispatch**, not arrival. Shipping remains
unselected because a login is required to quote it. Choose a quoted service with
actual Friday arrival; the Thursday dispatch needs next-day air. Product pages state
a 6 p.m. Eastern same-day cutoff. Keep the late parts out of this shipment.

### DigiKey — $21.50 parts; $49.17 estimated with selected freight/tariff

| Part | Buy qty | Unit price | Line total |
|---|---:|---:|---:|
| [XIAO ESP32C6 113991254](https://www.digikey.com/en/products/detail/seeed-technology-co-ltd/113991254/24613066) | 1 | $5.38 | $5.38 |
| [Radial Magnets 9042, Ø6×2.5 mm, diametric](https://www.digikey.com/en/products/detail/radial-magnets-inc/9042/5640338) | 2 | $0.63 | $1.26 |
| [SparkFun PRT-08808 / 08808 perfboard](https://www.digikey.com/en/products/detail/sparkfun-electronics/08808/7387401) | 1 | $2.96 | $2.96 |
| [6357 — AS5600 Magnetic Angle Sensor, STEMMA QT](https://www.digikey.com/en/products/detail/adafruit-industries-llc/6357/26832926) | 2 | $5.95 | $11.90 |

All four lines show Immediate availability. **FedEx Overnight P.M. Delivery is
selected at $26.99**; estimated tariffs about $0.68 (the October 7 estimate of $0.47,
scaled to the added spare board and magnet; recheck at checkout). Total is about
**$49.17 before tax**. One board and one magnet are spares.
The site warns of an additional business day for processing; dispatch by Thursday
October 8 is necessary for Friday. No destination-specific Friday guarantee is
displayed. The Adafruit 6357 board (1528-6357-ND) is in this overnight cart;
the separate Adafruit cart was emptied. MIKROE-4204 and the AS5601 fallback are absent.
Use direct VIN (3.3 V), GND, SCL and SDA wiring to the XIAO; no QT cable is needed.

### Hayward Home Depot — $3.97, bought

| Part | Buy qty | Pack / assembly use | Line total |
|---|---:|---|---:|
| [Everbilt M5×0.8×70 mm socket-head cap screw](https://www.homedepot.com/p/204283625) | 1 | two M5×0.8×70 socket-head screws; use one, one spare | $3.97 |

Model **844868**, Store SKU **540934**. **Bought in store at Hayward on October 7.**
The two-pack supplies one screw for the glove and one spare.

## Proper-build late shipment — $285.56 parts

Prepare these separately now so available parts can arrive as early as possible.
Dates are **dispatch dates**, not delivery promises. Shipping is unselected; login
is required to quote freight. Request partial shipment and the fastest quoted air
service so undated bearings do not hold the other parts.

| Part | Buy qty | Unit price | Line total | Displayed dispatch |
|---|---:|---:|---:|---|
| [GEAKB1.0-30-6-B-8N-QFC17-M3-LL](https://us.misumi-ec.com/vona2/detail/110300428430/?HissuCode=GEAKB1.0-30-6-B-8N-QFC17-M3-LL) | 2 | $42.51 | $85.02 | October 14 |
| [SSFRHQ8-20-F6-P5-T6-Q5-A12-KC8](https://us.misumi-ec.com/vona2/detail/110300088230/?HissuCode=SSFRHQ8-20-F6-P5-T6-Q5-A12-KC8) | 1 | $26.71 | $26.71 | October 14 |
| [MTA05-13ZZ DBS](https://us.misumi-ec.com/vona2/detail/221000531127/?HissuCode=MTA05-13ZZ%20DBS) | 3 | $23.58 | $70.74 | TBD; no date |
| [WSSAB10-5-1](https://us.misumi-ec.com/vona2/detail/110302677010/?HissuCode=WSSAB10-5-1) | 3 | $23.42 | $70.26 | October 10 |
| [KEG3-8](https://us.misumi-ec.com/vona2/detail/110302681730/?HissuCode=KEG3-8) | 2 | $3.90 | $7.80 | October 10 |
| [JPDPB2-3](https://us.misumi-ec.com/vona2/detail/110300557320/?HissuCode=JPDPB2-3) | 1 | $9.89 | $9.89 | October 15 |
| [AJKTNS5-70](https://us.misumi-ec.com/vona2/detail/110300599320/?HissuCode=AJKTNS5-70) | 1 | $15.14 | $15.14 | October 12 |

The shaft catalog normalizes the `A12-KC8` feature order; this is the same configured
shaft listed as `KC8-A12` in the BOM. Several parts will not arrive early next week:
the gears/shaft dispatch October 14 and the diamond pin October 15. The five custom
machined parts, one of each, remain outside these carts. The pending October 6
finalREV RFQ already covers this one-set scope. A quote, revised metal-thread
drawings and physical wrist verification are still required before release; no new
supplier message or machining order has been sent.

## Shared-pack count check

Counts include one robot and one glove, plus the extra inserts for the printed
coupler/flange. Pack counts were checked against product text/size diagrams.

| Required size / item | Needed | Available in selected shared packs | Result |
|---|---:|---:|---|
| M2×6 socket head | 12 | 30 | 18 spare |
| M2.5×6 / ×8 / ×10 socket head | 4 / 2 / 4 | 50 / 40 / 40 | One VGBUY kit covers all three |
| M2.5×15 socket head | 6 | 10 (one McMaster ten-pack) | 4 spare |
| M3×6 / ×8 / ×10 / ×12 standard socket head | 1 / 4 / 6 / 2 | 30 each | One ALLWIN kit covers all four |
| M3×6 low head / M3×8 low head / M2×8 low head | 6 / 4 / 2 | 25 / 25 / 10 | One of each McMaster low-head pack |
| M2×3 inserts | 8 | 60 in the M2–M5 kit | Includes 4 extra for the printed coupler |
| M2.5×4 inserts | 10 | 60 in the M2/M2.5 kit | One kit |
| M3×5 inserts | 6 | 50 in the M2–M5 kit | Includes 2 extra for the printed flange |
| M3×4 inserts | 2 | 50 in the M2–M5 kit | One kit |
| 695ZZ bearings | 3 | 10 | 7 spare; print 3 shims |
| M5×0.8×70 socket-head screws | 1 | 2 | Bought (Hayward two-pack); 1 spare |
| #16 return bands | 1 | 700 | One pack |
| Rubber pad pieces | 4 | Two 6×6 in (152×152 mm) Everbilt 1/16 in sheets, already owned | One sheet covers all four pieces |

The rubber meshes are about 83 mm long and 20/30 mm wide; one 152×152 mm sheet
has ample area for the four pad pieces with cutting allowance. Match Toyota's pad outlines
when cutting. Insert quantities cover the printed build; metal threads replace the
adapter inserts in the machined upgrade. Fit/strength checks remain as in the BOM.

## Cost and remaining delivery checks

| Group | Current amount | Basis |
|---|---:|---|
| Amazon | $153.70 | Parts; Prime deals not applied in guest cart; neoprene dropped |
| McMaster | $39.50 | Parts; freight unquoted |
| MISUMI stocked | $76.28 | Parts; freight unquoted |
| DigiKey | $49.17 | Parts (incl. spare board + magnet) + selected overnight freight + estimated tariffs |
| Hayward Home Depot | $3.97 | Bought October 7 |
| **Prototype/shared subtotal** | **$322.62** | Before tax and unquoted freight |
| MISUMI late | $285.56 | Parts; freight unquoted |
| **Prototype + proper-build carts** | **$608.18** | Before tax and unquoted freight; excludes custom machining |

Before placing orders:

1. Sign in to Amazon Prime and reconfirm the selected offers' delivery dates.
2. Obtain MISUMI and McMaster shipping quotes with actual arrival to 94158.
3. Confirm DigiKey dispatch timing despite its processing warning; overnight now
   means Monday arrival, so two-day air ($13.99) may arrive the same day for less.
4. Request partial shipment for the late MISUMI parts.

Printing supplies, any missing hookup wire/solder/adhesive and custom machining are
outside these totals. Check KADRICK insert fit, the substituted rubber/band and
prototype assembly before running the robot; follow the printed prototype's motor
limits. Shared hardware is reused for the proper build rather than purchased twice.

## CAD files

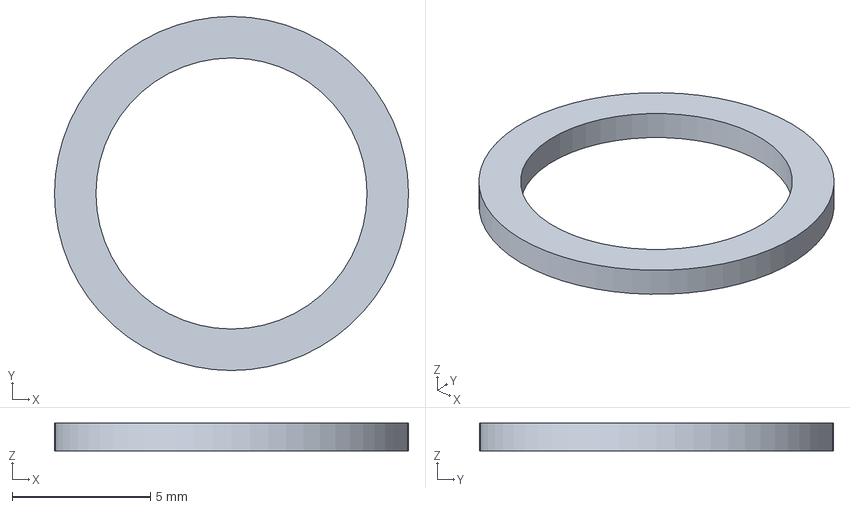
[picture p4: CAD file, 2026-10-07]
cad/out/printed/bearing_shim_1mm.step
12.8 x 12.8 x 1.00 mm

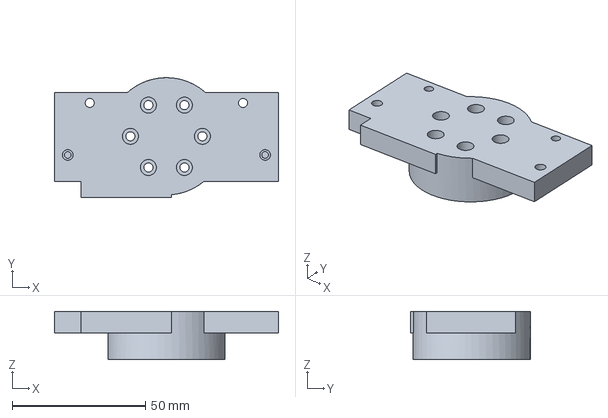
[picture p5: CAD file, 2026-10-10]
cad/out/yam_flange.step
84.0 x 44.9 x 18.0 mm

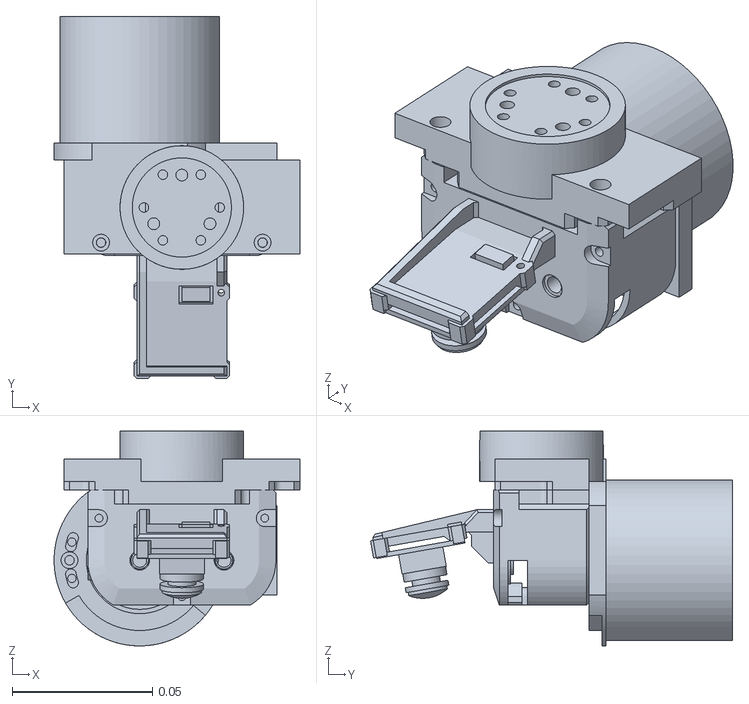
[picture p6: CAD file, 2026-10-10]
sdk/overlay/i2rt/robot_models/gripper/yubi_4310/assets/base.stl
0.0875 x 0.129 x 0.0765

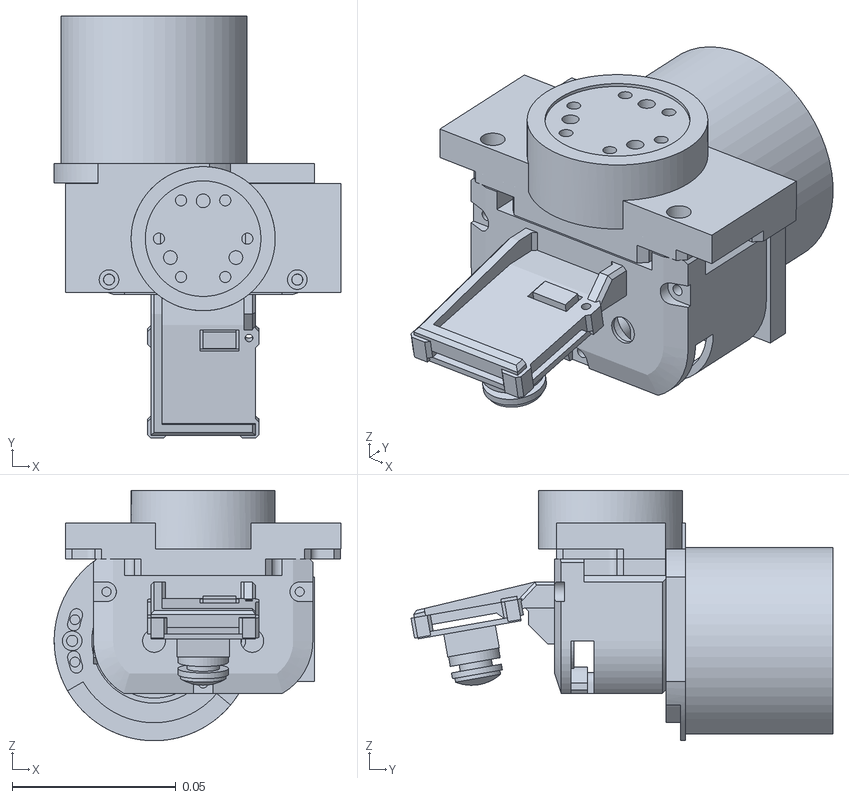
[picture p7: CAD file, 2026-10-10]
sim/assets/base_body.stl
0.0875 x 0.129 x 0.0765

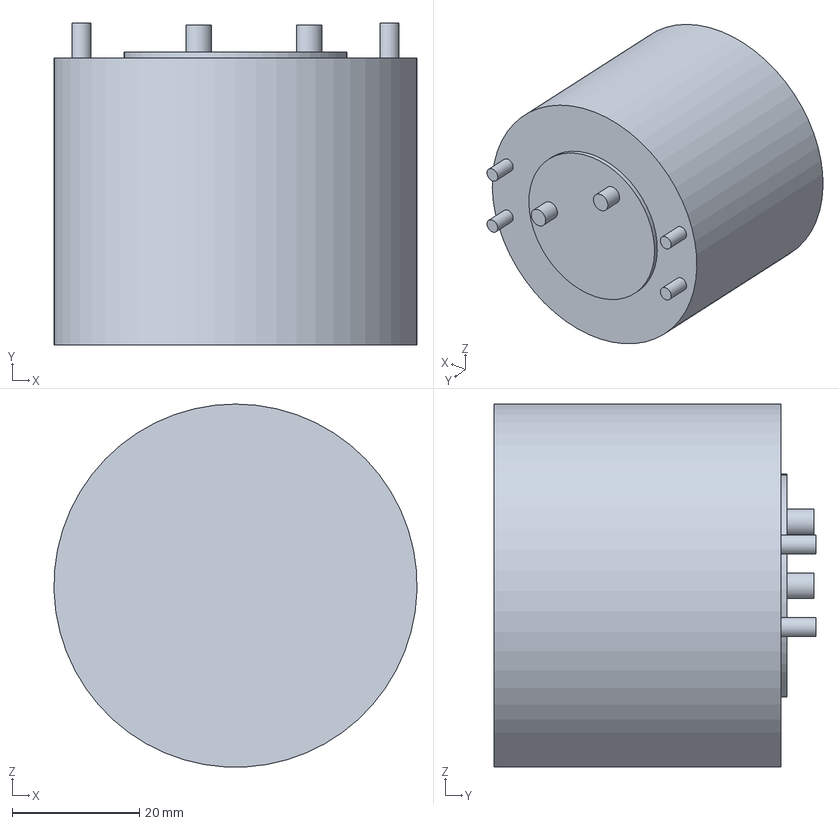
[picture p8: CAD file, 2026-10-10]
cad/out/dm4310_envelope_reference.step
57.0 x 50.5 x 57.0 mm

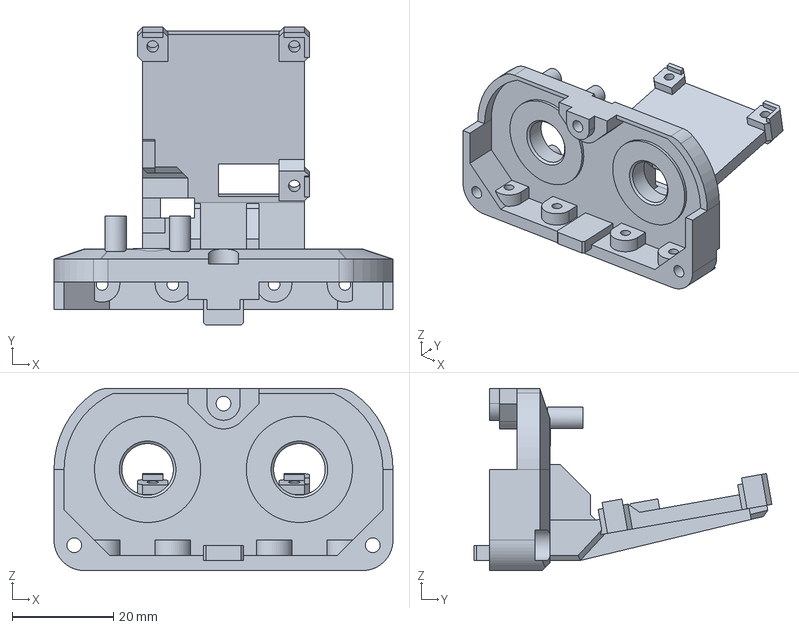
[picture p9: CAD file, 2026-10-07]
cad/out/printed/glove_upper_plate_as5600.step
67.0 x 58.9 x 36.0 mm

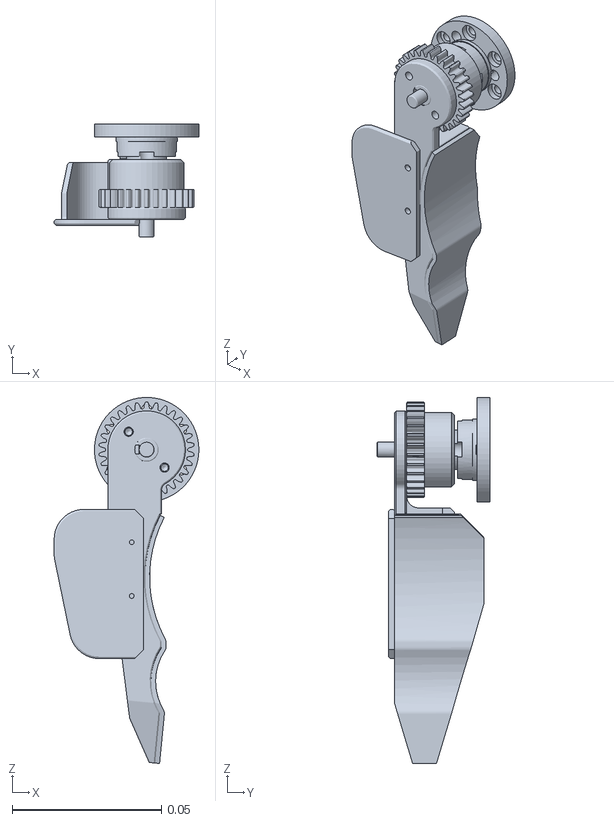
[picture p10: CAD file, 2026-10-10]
sdk/overlay/i2rt/robot_models/gripper/yubi_4310/assets/finger_r.stl
0.0485 x 0.038 x 0.123

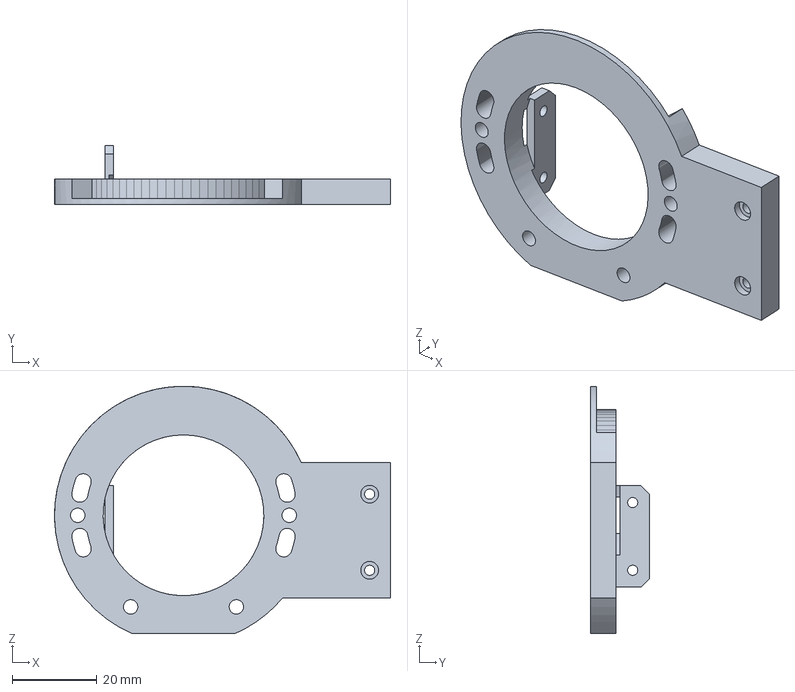
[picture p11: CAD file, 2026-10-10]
cad/out/motor_bracket.step
79.4 x 14.0 x 58.5 mm

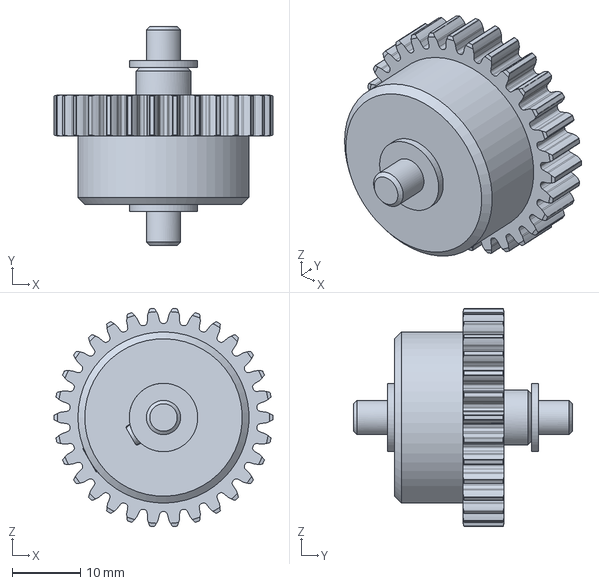
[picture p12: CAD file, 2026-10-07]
cad/out/printed/drive_L_printed.step
32.0 x 32.0 x 31.9 mm

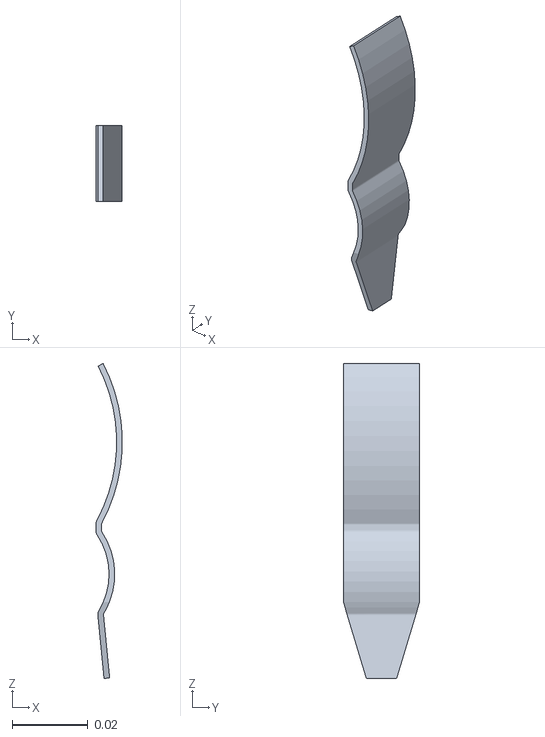
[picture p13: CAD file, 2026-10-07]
sdk/overlay/i2rt/robot_models/gripper/yubi_4310/assets/pad_l.stl
0.00697 x 0.02 x 0.0831

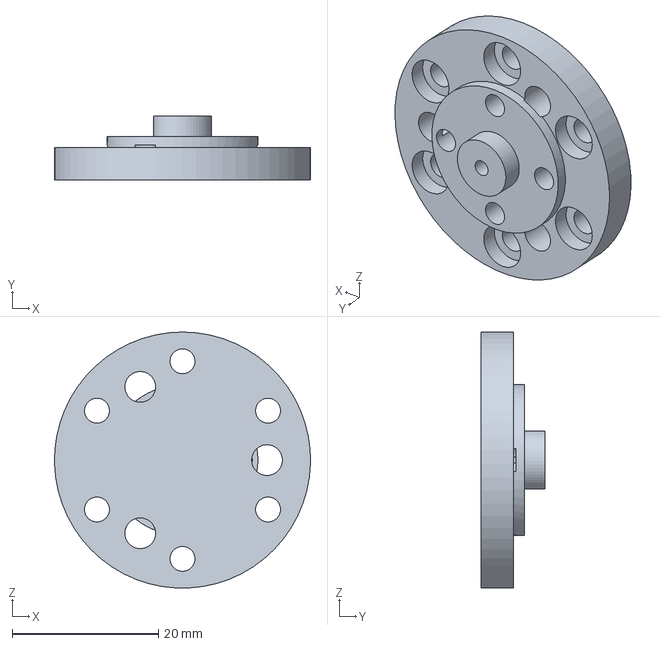
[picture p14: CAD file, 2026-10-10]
cad/out/coupler.step
35.0 x 8.80 x 35.0 mm

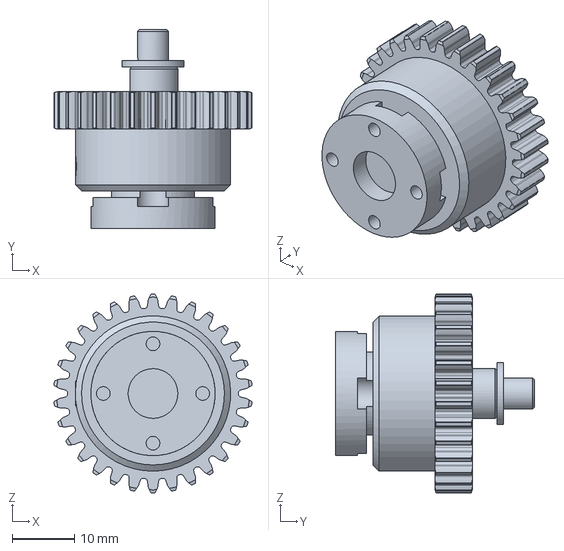
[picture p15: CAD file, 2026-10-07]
cad/out/printed/drive_R_printed.step
31.9 x 32.0 x 32.0 mm

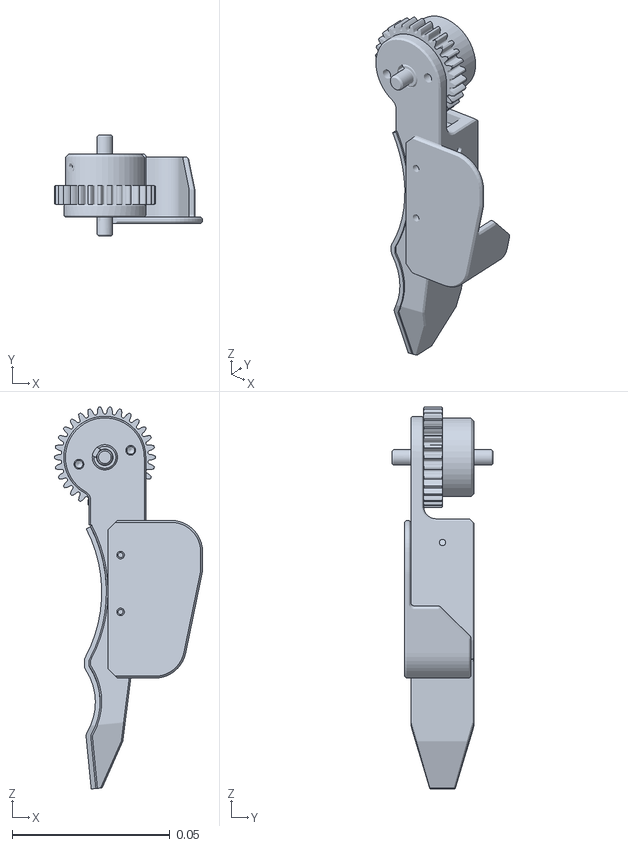
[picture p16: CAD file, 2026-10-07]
sdk/overlay/i2rt/robot_models/gripper/yubi_4310/assets/finger_l.stl
0.047 x 0.032 x 0.121

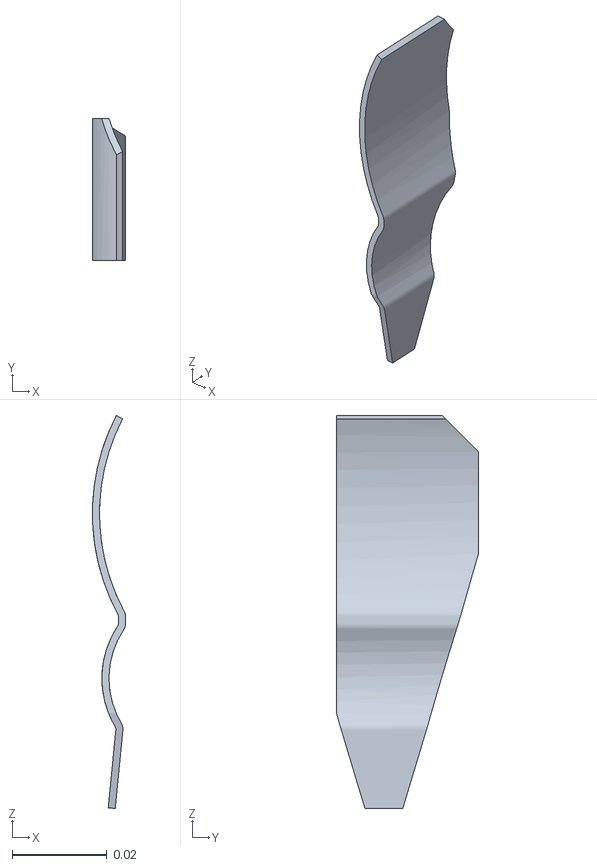
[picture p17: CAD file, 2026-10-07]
sim/assets/pad_r.stl
0.00698 x 0.03 x 0.0831

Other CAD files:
cad/out/bracket_trimmed.step
cad/out/bracket_trimmed.stl
cad/out/coupler.stl
cad/out/motor_bracket.stl
cad/out/printed/bearing_shim_1mm.stl
cad/out/printed/drive_L_printed.stl
cad/out/printed/drive_R_printed.stl
cad/out/printed/glove_upper_plate_as5600.stl
cad/out/yam_flange.stl
sim/assets/context.stl
sim/assets/finger_l_body.stl
sim/assets/finger_r_body.stl

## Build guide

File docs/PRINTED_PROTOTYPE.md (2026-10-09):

# Printed prototype (weekend build)

A first build of the YAM gripper and the gloves, made only from printed parts and
parts available within a couple of days in the US. It lets us test the mechanics,
wiring, Quest tracking and recording before the precision parts arrive.
The proper build (MISUMI gears and shaft, NSK bearings, machined adapters) replaces
it later; the glove is already the final design apart from its encoder board.
The current order covers **one robot gripper and one right-hand glove**. Print
Toyota's right-hand `FINGER with Gear_t30_R` / `FINGER with Gear_t20_L`,
`HOLDER_Quest_R`, `COVER_PCB_R` and `COVER_CABLE_R` for this glove.

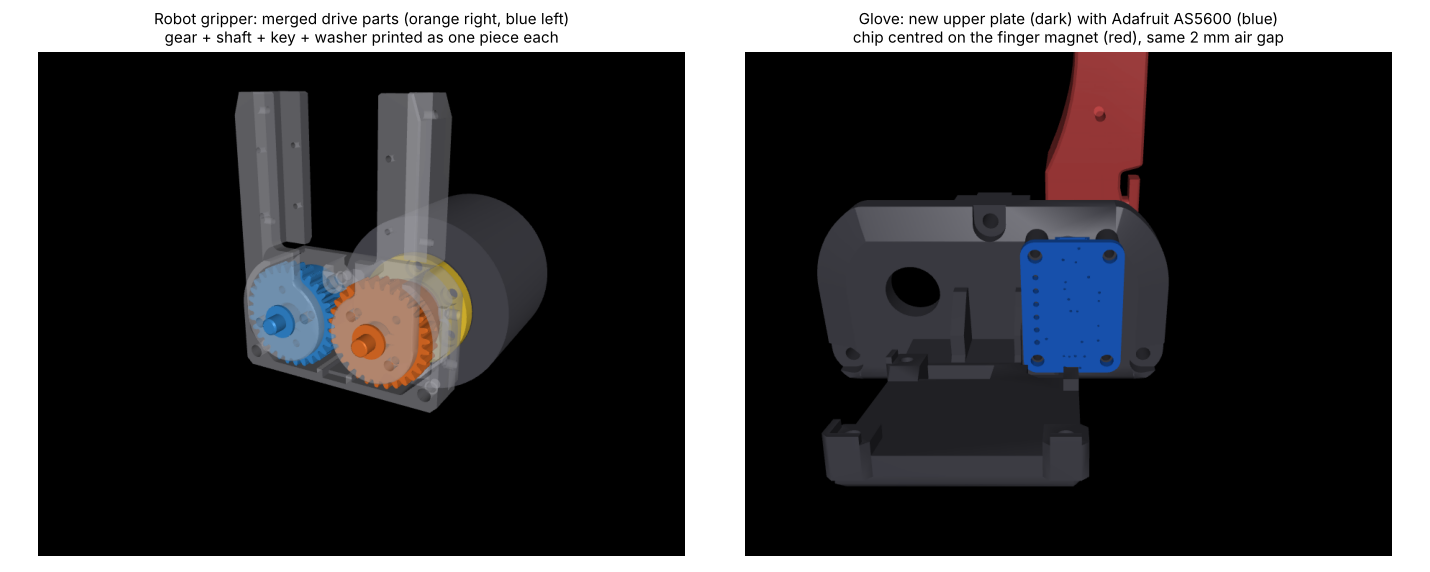
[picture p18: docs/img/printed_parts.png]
printed parts


Generated by `python3 cad/printed.py` (all files in `cad/out/printed/`), which also
checks every new part for interference against the Toyota assemblies (robot gripper,
left glove, right glove). Figure: `python3 docs/make_printed_figure.py`.

## Robot gripper: what changes

| Proper build | Printed prototype |
|---|---|
| Toyota `GEAR_SHAFT` (A2024) + MISUMI gear + key + washer | **`drive_R_printed`**: one printed part with the same outside shape |
| MISUMI stepped shaft + gear + key + 2 washers | **`drive_L_printed`**: one printed part |
| 3× NSK MTA05-13ZZ DBS (5×13×5) | 3× **695ZZ** (5×13×4) + 3× **`bearing_shim_1mm`** (one in each bearing seat, under the outer race) |
| machined coupler, motor bracket, trimmed bracket, wrist flange | printed from `cad/out/*.stl` as before (they were designed for heat-set inserts) |
| diamond locating pin (late) | leave out; the screws locate the parts well enough for a prototype |

Everything else (case, upper plate, finger attachments, pads, flaps) is Toyota's
printed design, as in the proper build.

**Printing the drive parts:** axis vertical, flange/large end on the bed, tree
supports under the gear. PETG or PLA+, 100 % infill, 0.12 mm layers for the teeth.
The Ø5 bearing journals usually print slightly oversize: sand or turn them in a drill
until the 695ZZ slides on with light force. The M3 holes in the gear face are at
tap-drill size; the finger-attachment screws self-tap into them.

**Go easy on the motor.** A DM4310 can strip printed teeth and twist a printed Ø8
shaft (roughly 3 N·m for PLA). Keep the default soft gains (`motor_kp 10`,
`motor_kd 0.3` in `yubi_4310.yml`) and limit the motor current so grip torque stays
around 1 N·m (about 12 N at the pads), which is enough for wires and connectors.

## Glove: AS5600 instead of AS5601

Toyota's encoder board (Switch Science #3494, AS5601) ships from Japan. The
prototype, and the final glove if it works well, uses the
**[Adafruit 6357 AS5600 breakout](https://www.adafruit.com/product/6357)** instead:

- **Firmware unchanged.** AS5600 and AS5601 share the I2C address (0x36) and every
  register yubi-sw's `ESP32C6_AS5601` firmware reads (status 0x0B, raw angle 0x0C,
  AGC 0x1A, magnitude 0x1B), so the firmware works without changes.
- **New upper plate, `glove_upper_plate_as5600`.** Toyota's plate with the two AS5601
  bosses removed and four new bosses that match the Adafruit board's corner holes.
  The board sits exactly where the AS5601 was: chip centred on the finger magnet,
  same 2.0 mm air gap, components facing the magnet, 1.5 mm clear of the finger.
  One plate fits both hands; Toyota uses the same upper plate for left and right.
- **Mounting:** 4× M2×6 socket head screws, self-tapping into the bosses (Ø1.7 pilots).
  Use the M2-only screw kit on the parts list, which explicitly lists 30 M2×6 screws.
  The original 888-piece mixed kit has M2×12/16 only and does not cover this mount.
  The two original CBSTNR3-5 encoder-mount screws per glove are no longer needed.
- **Wiring:** solder four wires to the header pads on the back (VIN to 3V3, GND, SCL,
  SDA) and run them to the XIAO as in Toyota's wiring. The STEMMA QT sockets face the
  magnet side and aren't used.
- **Magnet:** Ø6 × 2.5 mm, **diametrically** magnetised (DigiKey Radial Magnets 9042),
  in the finger's magnet pocket. The Adafruit board ships without one.

The board model used for the fit check is Adafruit's own
(`cad/vendor/adafruit_6357_as5600.step`, MIT licence).

## Order list changes from the original proper-build BOM

These changes are incorporated in [BOM_US.md](BOM_US.md). The
[proposed shopping list](SHOPPING_LIST_2026-10-09.md) uses one robot and one right-hand
glove, with one encoder board and one magnet installed plus one spare of each. All
glove-electronics lines are in the same overnight DigiKey cart. Grip rubber is the
Everbilt 1/16 in packing sheet Janos already has (tested on wires).

| Change | Per gripper / glove |
|---|---|
| add 695ZZ bearings, 5×13×4 mm | 3 per gripper |
| add M5×0.8 × 70 mm socket head screw (stands in for the late AJKTNS5-70) | 1 per glove |
| encoder board: **Adafruit 6357** instead of MIKROE-4204 (the Mikroe board is 28.6×25.4 mm and doesn't fit the glove) | 1 per glove |
| add M2×6 socket head screws for the board (covered by the replacement M2-only kit) | 4 per glove; 12 total with the original 4 robot + 4 glove screws |
| remove CBSTNR3-5 encoder-mount screws | 2 per glove |
| Radial Magnets 9042 diametric magnet; not included with the board | 1 for this glove (+1 spare) |
| skip for now: gears, stepped shaft, keys, precision washers, NSK bearings, diamond pin, machining | |

## Print list for this order

| Part | Source | Qty (1 gripper + 1 glove) |
|---|---|---|
| `drive_R_printed`, `drive_L_printed` | `cad/out/printed/` | 1 each |
| `bearing_shim_1mm` | `cad/out/printed/` | 3 |
| `coupler`, `motor_bracket`, `bracket_trimmed`, `yam_flange` | `cad/out/` | 1 each |
| case, upper plate, finger attachments L/R, pads, flaps | Toyota `STL/gripper` | per Toyota BOM |
| `glove_upper_plate_as5600` | `cad/out/printed/` (replaces Toyota's glove upper plate) | 1 |
| under plate, fingers with gear, flaps, grip, Quest holder, PCB/cable covers | Toyota `STL/glove`, right-hand parts as listed above | per Toyota BOM |

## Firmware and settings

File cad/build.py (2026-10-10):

"""Build the yubi-yam parts from Toyota's YUBI gripper CAD.

Run from the repo root (needs the third_party/yubi-hw submodule):

    python3 cad/build.py

What it does
  1. Loads Toyota's robot-side YUBI gripper assembly (Dynamixel version) with
     every part placed in assembly coordinates.
  2. Builds the four parts that turn it into a YAM gripper driven by a DM4310:
       coupler          replaces the Dynamixel horn (DM4310 rotor -> YUBI gear shaft)
       motor_bracket    holds the DM4310 behind the case, using the case's M2 inserts
       bracket_trimmed  Toyota's BRACKET_GRIPPER, cut back to clear the larger motor
       yam_flange       YAM wrist output -> bracket (replaces Toyota's UR5e flange)
  3. Checks every new part against every kept Toyota part and the motor for
     interference, and fails loudly if anything overlaps.
  4. Writes STEP + STL for the new parts to cad/out/, and the rigid-body meshes
     the MuJoCo model needs (in the i2RT gripper frame, metres) to sim/assets/.

All coordinates below are Toyota assembly coordinates in millimetres unless a
name says otherwise. The yubi-yam gripper frame is defined in GRIPPER_FRAME.
"""
from __future__ import annotations

import json
import math
import os
import re
import sys
from dataclasses import dataclass, asdict

import cadquery as cq
import numpy as np
import trimesh
from OCP.BRep import BRep_Tool
from OCP.BRepAlgoAPI import BRepAlgoAPI_Common
from OCP.BRepBuilderAPI import BRepBuilderAPI_Transform
from OCP.BRepGProp import BRepGProp
from OCP.BRepMesh import BRepMesh_IncrementalMesh
from OCP.GProp import GProp_GProps
from OCP.STEPCAFControl import STEPCAFControl_Reader
from OCP.TCollection import TCollection_ExtendedString
from OCP.TDF import TDF_ChildIterator, TDF_Label
from OCP.TDataStd import TDataStd_Name
from OCP.TDocStd import TDocStd_Document
from OCP.TopAbs import TopAbs_FACE, TopAbs_REVERSED
from OCP.TopExp import TopExp_Explorer
from OCP.TopLoc import TopLoc_Location
from OCP.TopoDS import TopoDS
from OCP.XCAFDoc import XCAFDoc_DocumentTool
from OCP.gp import gp_Trsf

ROOT = os.path.dirname(os.path.dirname(os.path.abspath(__file__)))
TOYOTA_ASSY = os.path.join(ROOT, "third_party/yubi-hw/STEP/gripper/YUBI Gripper Assy_Dynamixel_ver2.STEP")
OUT = os.path.join(ROOT, "cad/out")
SIM_ASSETS = os.path.join(ROOT, "sim/assets")


# --------------------------------------------------------------------------------------
# Parameters
# --------------------------------------------------------------------------------------
@dataclass
class WristInterface:
    """YAM joint-6 output, where a gripper bolts on.

    Not published by i2RT. The default assumes the gripper bolts straight onto a
    DM4310 rotor (the YAM's last link is 57 mm wide, the 4310's diameter): 6x M3 on a
    27 mm circle around a 35 mm boss. Verify on the arm and change here if it differs.
    """
    bolt_circle_d: float = 27.0
    bolt_count: int = 6
    bolt_clearance_d: float = 3.4      # M3
    head_counterbore_d: float = 6.0    # M3 socket head
    pilot_d: float = 35.3              # recess that centres on the 35 mm rotor boss
    pilot_depth: float = 0.8
    phase_deg: float = 0.0             # rotation of the bolt pattern about the wrist axis
    # If the wrist output is the same motor face as the gripper motor (measured), it also
    # has 2x Ø4 pins, 4.2 proud, on PCD 23.1 midway between bolts: the flange gets pockets
    # at all three midway positions so they fit whichever two are pinned.
    pin_pcd: float = 23.1
    pin_pocket_d: float = 4.2
    pin_pocket_depth: float = 4.8      # above the rotor face (pins stand 4.2)


@dataclass
class Params:
    wrist: WristInterface
    # DM4310 (Damiao DM-J4310-2EC), dimensions checked against Damiao's model as
    # published in OpenArm v1.1: body 57 x 45 mm, rotor boss 35 x 1 mm, rotor
    # 6x M3 on PCD 27, stator front ring 6x M3 on PCD 50, back 4x M3 on PCD 38.
    motor_d: float = 57.0
    motor_body_len: float = 45.0
    motor_boss_d: float = 35.0
    motor_boss_len: float = 1.0
    motor_rotor_pcd: float = 27.0
    motor_stator_pcd: float = 50.0
    motor_clock_deg: float = 0.0       # stator holes at 0, 60, ... deg in the XZ plane
    # Locating pins, measured on the YAM's gripper motor (label RD-J10D, DM4310 size):
    # rotor: 2x Ø4 pins standing 4.2 proud, 120 deg apart on PCD 23.1 (24 over both
    # pins), each midway between two rotor screw holes; the third midway hole is empty.
    rotor_pin_d: float = 4.0
    rotor_pin_pcd: float = 23.1
    rotor_pin_len: float = 4.2
    # stator ring: 2x Ø3 pins standing 5.5 proud, opposite each other on PCD 50,
    # each 15 deg (6.5 mm) from a screw hole. Which side of the hole is not known for
    # sure, so the bracket clears both sides.
    stator_pin_d: float = 3.0
    stator_pin_len: float = 5.5
    stator_pin_offset_deg: float = 15.0
    # The thick right finger pad (PAD_t30_R) reaches 3 mm behind the case, at 82-107 deg
    # around the shaft and >= 26.6 mm out. The bracket gets a relief over the arc the pad
    # sweeps, and the stator screws inside that arc are left out (4 of 6 used).
    pad_relief_deg: tuple = (40.0, 150.0)
    pad_relief_r: float = 25.0          # pad's closest point is 26.6 mm out
    pad_relief_y: float = 835.0         # pad reaches back to y = 836.5
    # Driven gear shaft (Toyota GEAR_SHAFT), axis along +Y
    shaft_x: float = 839.07
    shaft_z: float = 1270.57
    shaft_face_y: float = 840.5        # end face that the Dynamixel horn bolted to
    shaft_horn_pcd: float = 16.0       # 4x M2 through the shaft flange into the horn
    shaft_pilot_d: float = 8.0         # recess in the shaft end, 3 mm deep
    shaft_pilot_depth: float = 3.0
    case_back_y: float = 839.5         # back face of Toyota CASE
    case_hole_d: float = 22.0          # hole in the case back the horn used to enter
    # Layout choices
    bracket_plate_t: float = 6.0       # motor bracket plate thickness (Y)
    flange_under_motor_y: float = 833.6  # flange plate runs back under the motor bracket foot
    flange_plate_t: float = 8.0
    flange_hub_d: float = 44.0
    flange_hub_h: float = 10.0         # hub below the plate; keeps the wide plate off the wrist
    flange_plate_ymax: float = 873.0   # full width of Toyota's bracket
    trim_y: float = 839.6              # BRACKET_GRIPPER is cut away below this Y
    wrist_axis_x: float = 854.07       # centre of the two finger shafts
    wrist_axis_y: float = 856.5        # mid-plane of the finger attachments


P = Params(wrist=WristInterface())

# Derived positions
STATOR_FACE_Y = P.case_back_y - P.bracket_plate_t            # motor front ring sits on the bracket
ROTOR_FACE_Y = STATOR_FACE_Y + P.motor_boss_len               # coupler bolts here
FLANGE_TOP_Z = 1242.5735                                      # underside of BRACKET_GRIPPER (measured)
FLANGE_PLATE_BOT_Z = FLANGE_TOP_Z - P.flange_plate_t
WRIST_FACE_Z = FLANGE_PLATE_BOT_Z - P.flange_hub_h            # mates the YAM wrist output

# i2RT gripper frame: origin on the wrist output face, z along the wrist axis pointing
# away from the fingers (fingers at -z, as in i2RT's linear_4310 model), metres.
GRIPPER_FRAME_ORIGIN = np.array([P.wrist_axis_x, P.wrist_axis_y, WRIST_FACE_Z])
GRIPPER_FRAME_R = np.diag([1.0, -1.0, -1.0])


# --------------------------------------------------------------------------------------
# Toyota CAD
# --------------------------------------------------------------------------------------
def load_toyota_parts(path: str) -> dict[str, list]:
    """Leaf parts of a STEP assembly, placed in assembly coordinates, keyed by name."""
    if not os.path.exists(path):
        sys.exit(f"Toyota CAD not found at {path}\nRun: git submodule update --init third_party/yubi-hw")
    doc = TDocStd_Document(TCollection_ExtendedString("doc"))
    r = STEPCAFControl_Reader(); r.SetNameMode(True)
    if r.ReadFile(path) != 1:
        sys.exit(f"Could not read {path}")
    r.Transfer(doc)
    st = XCAFDoc_DocumentTool.ShapeTool_s(doc.Main())

    def name(l):
        n = TDataStd_Name()
        return n.Get().ToExtString() if l.FindAttribute(TDataStd_Name.GetID_s(), n) else "?"

    out: dict[str, list] = {}

    def walk(lbl, trsf, nm):
        ref = TDF_Label()
        if st.IsReference_s(lbl) and st.GetReferredShape_s(lbl, ref):
            walk(ref, trsf.Multiplied(st.GetLocation_s(lbl).Transformation()), name(ref)); return
        if st.IsAssembly_s(lbl):
            it = TDF_ChildIterator(lbl, False)
            while it.More():
                c = it.Value()
                if st.IsComponent_s(c):
                    walk(c, trsf, nm)
                it.Next()
            return
        placed = BRepBuilderAPI_Transform(st.GetShape_s(lbl), trsf, True).Shape()
        out.setdefault(nm.replace(" ", "_"), []).append(cq.Shape.cast(placed))

    it = TDF_ChildIterator(st.Label(), False)
    while it.More():
        l = it.Value()
        if st.IsFree_s(l) and st.IsShape_s(l):
            walk(l, gp_Trsf(), name(l))
        it.Next()
    return out


def one(parts, name):
    s = parts[name]
    assert len(s) == 1, (name, len(s))
    return s[0]


# --------------------------------------------------------------------------------------
# Geometry helpers
# --------------------------------------------------------------------------------------
def cyl_y(d, y0, y1, x, z):
    """Solid cylinder along +Y from y0 to y1 centred on (x, z)."""
    return cq.Solid.makeCylinder(d / 2, y1 - y0, cq.Vector(x, y0, z), cq.Vector(0, 1, 0))


def cyl_z(d, z0, z1, x, y):
    return cq.Solid.makeCylinder(d / 2, z1 - z0, cq.Vector(x, y, z0), cq.Vector(0, 0, 1))


def cyl_x(d, x0, x1, y, z):
    return cq.Solid.makeCylinder(d / 2, x1 - x0, cq.Vector(x0, y, z), cq.Vector(1, 0, 0))


def box(x0, x1, y0, y1, z0, z1):
    return cq.Solid.makeBox(x1 - x0, y1 - y0, z1 - z0, cq.Vector(x0, y0, z0))


def polar(cx, cz, r, deg):
    a = math.radians(deg)
    return cx + r * math.cos(a), cz + r * math.sin(a)


def volume(shape) -> float:
    g = GProp_GProps(); BRepGProp.VolumeProperties_s(shape.wrapped, g)
    return g.Mass()


def common_volume(a, b) -> float:
    op = BRepAlgoAPI_Common(a.wrapped, b.wrapped)
    op.Build()
    if not op.IsDone():
        return float("nan")
    return volume(cq.Shape.cast(op.Shape()))


# --------------------------------------------------------------------------------------
# New parts
# --------------------------------------------------------------------------------------
def stator_pin_angles():
    """Both candidate positions of the two stator-ring pins (15 deg either side of the
    holes at 0 and 180 deg); the bracket clears all four, the motor sits in either way."""
    o = P.stator_pin_offset_deg
    return [P.motor_clock_deg + b + s * o for b in (0, 180) for s in (-1, 1)]


def rotor_pin_angles():
    """Midway between rotor screws (which sit at 30 + 60k): the coupler gets a pocket at
    three of these, 120 deg apart, so the rotor's two pins fit in any of three clockings."""
    return [0.0, 120.0, 240.0]


def make_motor(with_pins=True):
    """DM4310 envelope, output facing +Y onto the driven shaft (reference only).
    Includes the measured locating pins (stator pins at every candidate position)."""
    x, z = P.shaft_x, P.shaft_z
    body = cyl_y(P.motor_d, STATOR_FACE_Y - P.motor_body_len, STATOR_FACE_Y, x, z)
    boss = cyl_y(P.motor_boss_d, STATOR_FACE_Y, ROTOR_FACE_Y, x, z)
    m = body.fuse(boss)
    if with_pins:
        for a in stator_pin_angles():
            px, pz = polar(x, z, P.motor_stator_pcd / 2, a)
            m = m.fuse(cyl_y(P.stator_pin_d, STATOR_FACE_Y, STATOR_FACE_Y + P.stator_pin_len, px, pz))
        for a in rotor_pin_angles()[:2]:
            px, pz = polar(x, z, P.rotor_pin_pcd / 2, a)
            m = m.fuse(cyl_y(P.rotor_pin_d, ROTOR_FACE_Y, ROTOR_FACE_Y + P.rotor_pin_len, px, pz))
    return m.clean()


def make_coupler():
    """DM4310 rotor (6x M3, PCD 27) -> YUBI gear shaft (4x M2 inserts, PCD 16, 8 mm pilot).

    Reproduces the Dynamixel horn interface on the shaft side, so Toyota's GEAR_SHAFT
    and its screws are used unchanged.
    """
    disk_d, neck_d = 35.0, 20.6
    disk_end = P.case_back_y - 0.5                     # 0.5 mm clear of the case back
    x, z = P.shaft_x, P.shaft_z
    c = cyl_y(disk_d, ROTOR_FACE_Y, disk_end, x, z)
    c = c.fuse(cyl_y(neck_d, disk_end, P.shaft_face_y, x, z))
    c = c.fuse(cyl_y(P.shaft_pilot_d - 0.1, P.shaft_face_y, P.shaft_face_y + P.shaft_pilot_depth - 0.2, x, z))
    # rotor screws: M3 through, heads counterbored into the shaft-side face of the disk
    for k in range(6):
        hx, hz = polar(x, z, P.motor_rotor_pcd / 2, 30 + 60 * k)
        c = c.cut(cyl_y(3.4, ROTOR_FACE_Y - 1, disk_end + 1, hx, hz))
        c = c.cut(cyl_y(6.0, disk_end - 2.2, disk_end + 1, hx, hz))
    # shaft screws: M2 heat-set inserts (Toyota's SB-203030, 3.0 OD x 3 mm) at PCD 16
    for k in range(4):
        hx, hz = polar(x, z, P.shaft_horn_pcd / 2, 90 * k)
        c = c.cut(cyl_y(3.1, P.shaft_face_y - 3.3, P.shaft_face_y + 1, hx, hz))
        c = c.cut(cyl_y(1.8, P.shaft_face_y - 5.5, P.shaft_face_y, hx, hz))
    # pockets for the rotor's Ø4 locating pins (3 positions, pins use 2); 0.2 clearance
    for a in rotor_pin_angles():
        hx, hz = polar(x, z, P.rotor_pin_pcd / 2, a)
        c = c.cut(cyl_y(P.rotor_pin_d + 0.2, ROTOR_FACE_Y - 1, ROTOR_FACE_Y + P.rotor_pin_len + 0.6, hx, hz))
    # centre M2.5 (optional, as on the horn): self-tapping pilot
    c = c.cut(cyl_y(2.1, P.shaft_face_y - 4.0, P.shaft_face_y + P.shaft_pilot_depth, x, z))
    return c.clean()


def sector_y(r_in, r_out, a0, a1, y0, y1, cx, cz, steps=24):
    """Annular sector prism along +Y (angles in deg, measured in the XZ plane)."""
    outer = [polar(cx, cz, r_out, a0 + (a1 - a0) * i / steps) for i in range(steps + 1)]
    inner = [polar(cx, cz, r_in, a1 - (a1 - a0) * i / steps) for i in range(steps + 1)]
    pts = [cq.Vector(px, y0, pz) for px, pz in outer + inner]
    face = cq.Face.makeFromWires(cq.Wire.makePolygon(pts, close=True))
    return cq.Solid.extrudeLinear(face, cq.Vector(0, y1 - y0, 0))


def stator_holes():
    """Stator screw angles actually used (those outside the pad relief)."""
    a0, a1 = P.pad_relief_deg
    return [a for a in (P.motor_clock_deg + 60 * k for k in range(6)) if not (a0 - 8 <= a % 360 <= a1 + 8)]


def make_motor_bracket(toyota):
    """Plate behind the case: holds the DM4310 by its front ring, bolts to the case.

    The case-side features (side tab with 2x M2 into the case's side inserts) are
    taken directly from Toyota's BRACKET_DYNAMIXEL, so they match the case exactly.
    """
    y0, y1 = STATOR_FACE_Y, P.case_back_y
    x, z = P.shaft_x, P.shaft_z
    plate = cyl_y(61.0, y0, y1, x, z)
    plate = plate.fuse(box(x, 888.0, y0, y1, 1251.0, 1283.0))           # arm to the back inserts
    plate = plate.fuse(box(820.57, x, y0, y1, 1252.0, 1283.0))          # web to the side tab
    # flat foot resting on the wrist flange: a second load path for the motor's
    # weight (325 g vs the Dynamixel's 82 g) besides the four M2 screws into the case
    plate = plate.cut(box(700, 1000, y0 - 1, y1 + 1, 0, FLANGE_TOP_Z))
    # Toyota's side tab: everything of BRACKET_DYNAMIXEL in front of the plate
    dyn = one(toyota, "BRACKET_DYNAMIXEL")
    tab = dyn.intersect(box(815, 830, y1, 860, 1240, 1300))
    plate = plate.fuse(tab)
    # bore for the rotor boss and coupler
    plate = plate.cut(cyl_y(38.0, y0 - 1, y1 + 1, x, z))
    # relief for the swept finger pad
    a0, a1 = P.pad_relief_deg
    plate = plate.cut(sector_y(P.pad_relief_r, 45.0, a0, a1, P.pad_relief_y, y1 + 1, x, z))
    # M3 into the stator ring (outside the relief), heads counterbored on the case side
    for ang in stator_holes():
        hx, hz = polar(x, z, P.motor_stator_pcd / 2, ang)
        plate = plate.cut(cyl_y(3.4, y0 - 1, y1 + 1, hx, hz))
        plate = plate.cut(cyl_y(6.0, y1 - 2.0, y1 + 1, hx, hz))   # DIN 7984 head (2.0) flush;
        # M3x8 then engages 4.0 of the ring's ~4.8 deep threads
    # slots for the stator ring's Ø3 locating pins (5.5 proud), both candidate sides
    for ang in stator_pin_angles():
        r = P.motor_stator_pcd / 2
        w = P.stator_pin_d / 2 + 0.4
        plate = plate.cut(sector_y(r - w, r + w, ang - 3.5, ang + 3.5, y0 - 1, y1 + 1, x, z))
        for e in (ang - 3.5, ang + 3.5):
            ex, ez = polar(x, z, r, e)
            plate = plate.cut(cyl_y(2 * w, y0 - 1, y1 + 1, ex, ez))
    # 2x M2 into the case back inserts (Toyota positions), heads on the motor side
    for zz in (1257.57, 1275.57):
        plate = plate.cut(cyl_y(2.4, y0 - 1, y1 + 1, 883.07, zz))
        plate = plate.cut(cyl_y(4.2, y0 - 1, y0 + 1.6, 883.07, zz))
    return plate.clean()


def make_bracket_trimmed(toyota):
    """Toyota BRACKET_GRIPPER with the part under the motor removed."""
    b = one(toyota, "BRACKET_GRIPPER")
    return b.cut(box(700, 1000, 700, P.trim_y, 1000, 1400)).clean()


def make_yam_flange():
    """Plate under the trimmed bracket + hub that bolts to the YAM wrist output."""
    w = P.wrist
    cx, cy = P.wrist_axis_x, P.wrist_axis_y
    f = box(812.1, 896.1, P.trim_y, P.flange_plate_ymax, FLANGE_PLATE_BOT_Z, FLANGE_TOP_Z)
    # shelf under the motor bracket foot (motor body itself starts at y = 833.5)
    f = f.fuse(box(822.0, 856.0, P.flange_under_motor_y, P.trim_y, FLANGE_PLATE_BOT_Z, FLANGE_TOP_Z))
    f = f.fuse(cyl_z(P.flange_hub_d, WRIST_FACE_Z, FLANGE_TOP_Z, cx, cy))
    # wrist bolts: through, heads counterbored from the top (fit before the bracket)
    for k in range(w.bolt_count):
        a = math.radians(w.phase_deg + 360.0 * k / w.bolt_count)
        hx, hy = cx + w.bolt_circle_d / 2 * math.cos(a), cy + w.bolt_circle_d / 2 * math.sin(a)
        f = f.cut(cyl_z(w.bolt_clearance_d, WRIST_FACE_Z - 1, FLANGE_TOP_Z + 1, hx, hy))
        f = f.cut(cyl_z(w.head_counterbore_d, WRIST_FACE_Z + 6.0, FLANGE_TOP_Z + 1, hx, hy))
    f = f.cut(cyl_z(w.pilot_d, WRIST_FACE_Z - 1, WRIST_FACE_Z + w.pilot_depth, cx, cy))
    for k in range(3):
        a = math.radians(w.phase_deg + 180.0 / w.bolt_count + 120.0 * k)
        hx, hy = cx + w.pin_pcd / 2 * math.cos(a), cy + w.pin_pcd / 2 * math.sin(a)
        f = f.cut(cyl_z(w.pin_pocket_d, WRIST_FACE_Z - 1, WRIST_FACE_Z + w.pilot_depth + w.pin_pocket_depth, hx, hy))
    # Gripper -> flange, 4x M3:
    #  * 2x from the top through the bracket into M3 heat-set inserts (Toyota's bracket
    #    screws to the UR flange at these points; the other four fall in the trimmed area)
    for (ix, iy) in ((817.07, 849.5), (891.07, 849.5)):
        f = f.cut(cyl_z(4.0, FLANGE_TOP_Z - 5.5, FLANGE_TOP_Z + 1, ix, iy))
        f = f.cut(cyl_z(2.5, FLANGE_TOP_Z - 7.0, FLANGE_TOP_Z, ix, iy))
    #  * 2x from below through flange + bracket into the upper plate's inserts, at
    #    Toyota's upper-plate screw positions (M3x12 instead of Toyota's M3x8)
    for (ix, iy) in ((825.32, 869.0), (882.82, 869.0)):
        f = f.cut(cyl_z(3.4, FLANGE_PLATE_BOT_Z - 1, FLANGE_TOP_Z + 1, ix, iy))
        f = f.cut(cyl_z(6.0, FLANGE_PLATE_BOT_Z - 1, FLANGE_PLATE_BOT_Z + 4.0, ix, iy))
    return f.clean()


# --------------------------------------------------------------------------------------
# Meshing / export
# --------------------------------------------------------------------------------------
def to_trimesh(shape, tol=0.05) -> trimesh.Trimesh:
    s = shape.wrapped
    BRepMesh_IncrementalMesh(s, tol, False, 0.3, True)
    V, F, off = [], [], 0
    e = TopExp_Explorer(s, TopAbs_FACE)
    while e.More():
        f = TopoDS.Face(e.Current()); loc = TopLoc_Location(); t = BRep_Tool.Triangulation_s(f, loc)
        if t is not None:
            tr = loc.Transformation()
            for i in range(1, t.NbNodes() + 1):
                p = t.Node(i).Transformed(tr); V.append((p.X(), p.Y(), p.Z()))
            rev = f.Orientation() == TopAbs_REVERSED
            for i in range(1, t.NbTriangles() + 1):
                a, b, c = t.Triangle(i).Get()
                F.append((off + a - 1, off + c - 1, off + b - 1) if rev else (off + a - 1, off + b - 1, off + c - 1))
            off += t.NbNodes()
        e.Next()
    m = trimesh.Trimesh(np.array(V), np.array(F))
    m.merge_vertices()
    return m


def to_gripper_frame(m: trimesh.Trimesh) -> trimesh.Trimesh:
    m = m.copy()
    m.vertices = ((m.vertices - GRIPPER_FRAME_ORIGIN) @ GRIPPER_FRAME_R.T) / 1000.0
    return m


def to_gripper_point(p) -> list[float]:
    return (((np.asarray(p, float) - GRIPPER_FRAME_ORIGIN) @ GRIPPER_FRAME_R.T) / 1000.0).round(6).tolist()


SCREWS = re.compile(r"^(CB|CBE|CBSTNR|JP|SB-|XDSHC)")
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

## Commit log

2026-10-07 YUBI gripper for the I2RT YAM, driven by the stock DM4310
    Adapts Toyota/AIRoA's YUBI robot gripper to the YAM: a coupler and motor
    bracket replace the Dynamixel, a trimmed bracket and new wrist flange replace
    the UR5e mount. Includes the parametric CAD build, finger travel sweep, an
    i2RT SDK patch + gripper model/config, and MuJoCo checks (SDK path, grasp,
    reach vs the stock gripper).
    Claude-Session: https://claude.ai/code/session_01W7A3hdTQfLtEz3Wfsvadw1
    [base.stl, base_body.stl, bracket_trimmed.step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]
2026-10-07 Add US parts list with MISUMI part numbers and sizes from CAD
    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
2026-10-07 Update US BOM with priced sources, shipping checks and precision-part blockers
2026-10-07 Add fully printed prototype: merged drive parts, 695ZZ shims, AS5600 glove plate
    cad/printed.py builds a weekend version from parts available in the US now:
    - drive_R/L_printed: gear + shaft + key + washers merged into one printable
    part per finger, in place and shape of the bought parts
    - bearing_shim_1mm: lets 695ZZ (5x13x4) stand in for the NSK 5x13x5 bearings
    - glove_upper_plate_as5600: Toyota's glove plate re-bossed for the Adafruit
    6357 AS5600 board (same I2C address and registers as the AS5601, firmware
    unchanged); chip on the magnet axis with the same 2 mm air gap, fits both hands
    Interference-checked against the robot gripper and both glove assemblies.
    docs/PRINTED_PROTOTYPE.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
    [bearing_shim_1mm.step, bearing_shim_1mm.stl, drive_L_printed.step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]
2026-10-07 Correct shopping scope to two grippers and two gloves
2026-10-07 Reduce shopping scope to one gripper and one right glove
2026-10-09 Shopping list: drop neoprene, mark M5 screws bought, add spare AS5600 + magnet
    - Grip rubber: Janos already has Everbilt 1/16 in rubber sheet that grips wires
    well, so the neoprene sheet is dropped from the Amazon cart ($153.70).
    - M5x70 screws were bought at Hayward Home Depot on October 7.
    - DigiKey: second Adafruit 6357 and Radial 9042 as spares ($49.17 est.).
    - Status note: Friday cutoffs have passed for MISUMI, McMaster and DigiKey.
    Totals: $322.62 prototype/shared + $285.56 late = $608.18.
    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
2026-10-10 Fit coupler and motor bracket to the measured gripper motor's locating pins
    Measured on the YAM's gripper motor (RD-J10D, DM4310 face): rotor Ø35 with
    6x M3 on PCD 27 (>=7.5 deep), ring 6x M3 on PCD 50 (~4.8 deep), housing Ø57,
    all matching the CAD. New: 2x Ø4 rotor pins (4.2 proud, PCD 23.1, 120 deg)
    and 2x Ø3 ring pins (5.5 proud, opposite, 15 deg from a screw hole).
    - coupler: Ø4.2 pockets at the three midway positions between rotor screws
    - motor_bracket: short slots for the ring pins on both candidate sides; head
    counterbores 2.0 deep so M3x8 engages 4.0 of the ring's ~4.8 mm threads
    - motor envelope includes the pins; interference, travel sweep and sim
    checks all pass unchang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
    [base.stl, base_body.stl, coupler.step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]
2026-10-10 Wrist flange: pockets for Ø4 output pins, assuming the wrist has the same motor face
    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
    [base.stl, base_body.stl, yam_flange.step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]
